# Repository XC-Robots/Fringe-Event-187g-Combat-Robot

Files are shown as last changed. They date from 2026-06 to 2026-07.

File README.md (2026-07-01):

# Fringe-Event-187g-Combat-Robot
Fringe Event is a combat robot in the fairyweight weight class. It uses a compliant shuffling mechanism for locomotion. Its main weapon is a pair of forks that fold inwards, trapping its opponents. Fringe Event, evident in the name, is inspired by and themed on the tv show Fringe. Normal fairyweight robots are 150g, so you might wonder why this one is more. Since Fringe Event is a shuffler, it gets a 1.25x weight bonus. The goal of this build is to experiment with different methods of locomotion and offensive mechanisms. Below is the final render of the bot:FringeEventRender

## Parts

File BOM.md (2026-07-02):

| Item | Individual Weight (g) | Quantity | Spare Quantity | Individual Cost ($) | Total Cost w/ Shipping ($) | Total Weight on bot (g)| Link | Version|
|---|---|---|---|---|---|---|---|---|
| Drive Motors | 15.2 | 2 | 0 | 19.00 |43.97 | 30.4 | https://turnabot.com/products/planetary-gearbox-high-power-n10-n20-and-n30-motors?variant=42952334540865 | N20 1300
| LiPo Battery 2S | 19 | 1 | 0 | 26.99 |29.08 | 19 | https://www.amazon.com/OVONIC-300mAh-Battery-Voltage-Package/dp/B0D2L17M8H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 |
| Drive ESC | 2.5 | 1 | 0 | 28.00 | 33.97 | 2.5 | https://turnabot.com/products/malenki-nano-integrated-6-channel-triple-electronic-speed-controller-receiver-combo |
| Power Switch | 2.15 | 1 | 0 | 9.00 | 14.00 | 2.15 | https://repeat-robotics.com/products/fingertech-switch
| TPU Chassis | 44.5 | 1 | 1 | - | - | 44.5 | - |
| TPU Servo Guard | 10 | 1 | 1 | - | - | 10 | - |
| TPU Legs | 1 | 12 | 12 | - | - | 12 | - |
| PLA Cams | 0.26 | 6 | 6 | - | - | 1.6 | - |
| PLA Motor Mounts | 9.6 | 2 | 2 | - | - | 19.2 | - |
| Standoffs | 1 | 5 | 5 | 0.74 |  | 5 | https://www.mcmaster.com/95947A013/ |
| Servo | 20 | 1 | 0 | 35.00 | 41.24 | 20 | https://turnabot.com/products/kst-ds215mg |
| Top plate | 6.33 | 1 | 1 | 9.99 | 10.76 | 6.33 | https://www.amazon.com/Zonon-Polycarbonate-Plastic-Resistant-Document/dp/B0DGGMP8QB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 |
| Bottom plate | 7.23 | 1 | 1 | (purchased w/ top plate) | (purchased w/ top plate) | 7.23 | https://www.amazon.com/Zonon-Polycarbonate-Plastic-Resistant-Document/dp/B0DGGMP8QB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 |
| Forks | 4 | 2 | 2 | 2.05 | 32.21 | 4 | Sendcutsend |
| **TOTALS** | - | - | - | - | 205.23 | 183.91 | - |

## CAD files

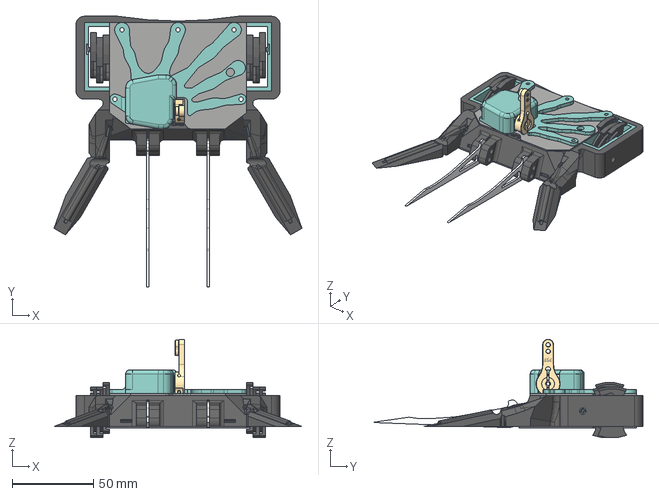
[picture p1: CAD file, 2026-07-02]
CAD/Fringe Event Full Bot.step
152.3 x 166.1 x 60.4 mm

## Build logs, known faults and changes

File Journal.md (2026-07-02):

Day 1, 6/28/26:    
Today I began working on the electronics layout of my robot. For decent pushing power and little weight usage I decided to go with planetary n20s for my robot's drive system. To keep things simple and compact, I am controlling these through a Malenki-Nano board, which handles both the drive controller and reciever jobs. To operate the hugging mechanism I am using a KST DS215MG servo, mainly for its speed and reliability. All this is powered by a 2S 300mAh battery. Below is my current electronics positioning. This took around 20 minutes of work.

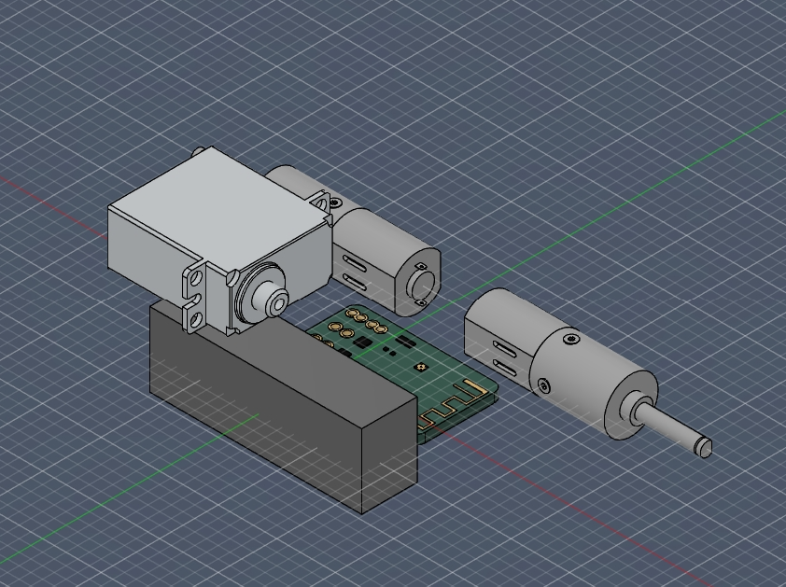
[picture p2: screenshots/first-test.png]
Electronics setup


Day 2, 6/29/26:
I designed a rough TPU chassis to fit around the electronics, as well as polycarbonate top and bottom plates. I decided to use M2.5 aluminum standoffs to hold everything together. This process took 37 minutes.
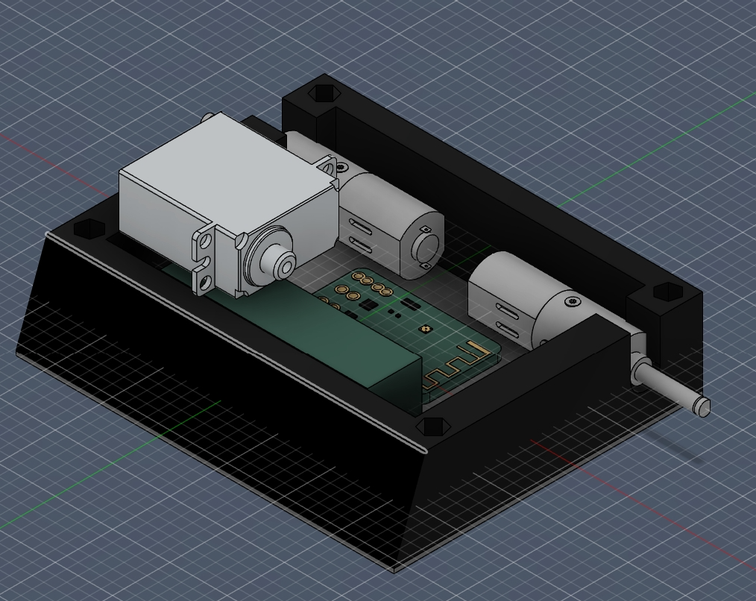
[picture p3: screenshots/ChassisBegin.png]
Chassis setup

Working on the basis of the drive motor mount and cam for the shuffler mechanism. The shuffler mechanism is inspired by this design: https://www.digikey.com/en/maker/tutorials/2024/how-to-make-a-robot-shuffler-mechanism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. I am planning on printing this out of PLA+ or PETG since this part is caged in TPU and therefore won't need to take a direct hit, and it'll keep things simple. Also made significant changes to chassis in order to fit this new portion. I removed the side walls and back wall, which I will add back in later once the essentials are in place. This has taken 45 minutes so far. Here is my motor mount:
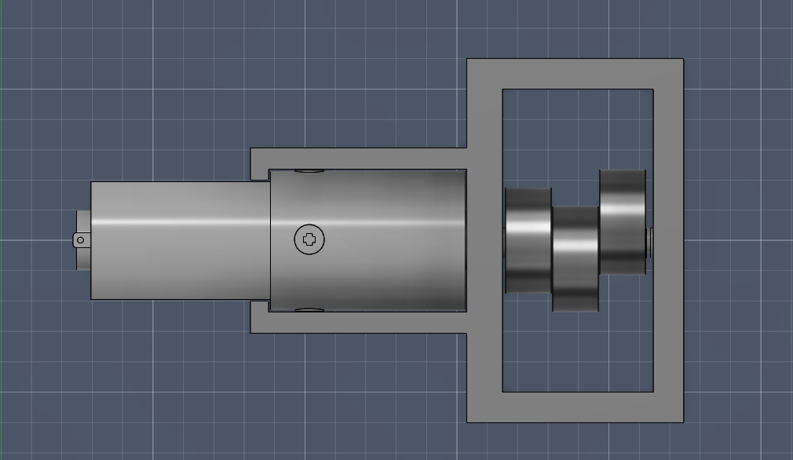
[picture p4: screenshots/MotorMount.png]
Motor

      I spent a good hour working on the shuffler legs, adjusting them to fit the robot. I went for three legs per side to enduce clean motion without using too much weight. Since I am using a compliant shuffler mechanism, I will be printing these legs out of TPU. I also remade the TPU chassis and armor, fitting it better to the overall design.
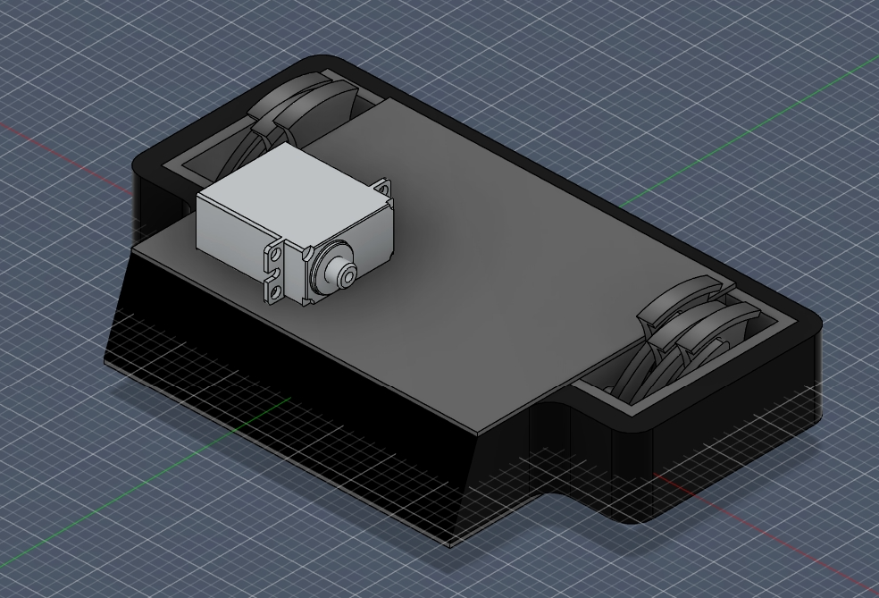
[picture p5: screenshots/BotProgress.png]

       I spent 36 minutes refining the details, mostly the coloration, of the robot. I also took the time to start on one of the hugger forks. These will hang around around the outside of the bot and then snap inwards when triggered by the servo. Just a rough draft right now.
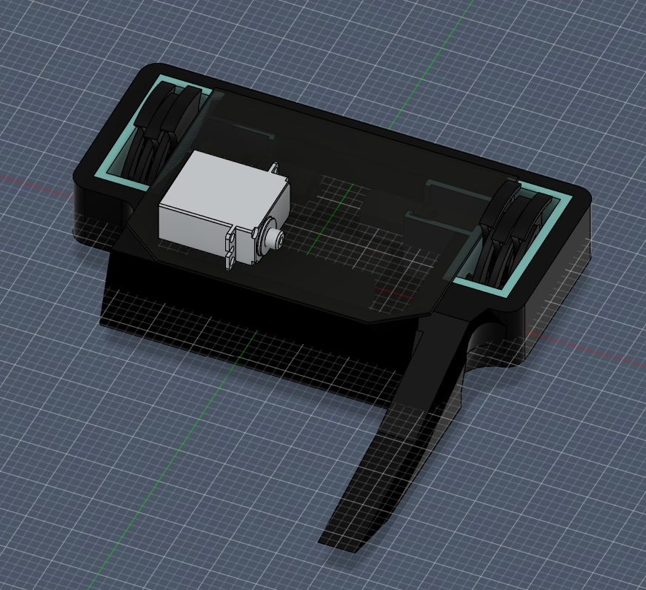
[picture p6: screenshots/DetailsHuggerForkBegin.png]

         Day 3, 6/30/26:
     I took the time to refine the current details in the robot, filleting and chamfering where needed. I also added the holes for the standoffs I'm going to use to connect the top and bottom plates, as well as refined the motor mounts and indented the back TPU armor (this with the purpose of saving weight and looking cooler). This process took 40 minutes. I spent another 34 minutes coming up with and editing a design for the inner forks. To compliment the hugger forks, I am using two standard forks between them, made out of 1.5mm aluminum. This will significantly increase the likelyhood of getting under enemy robots, which is crucial to combat robotics.

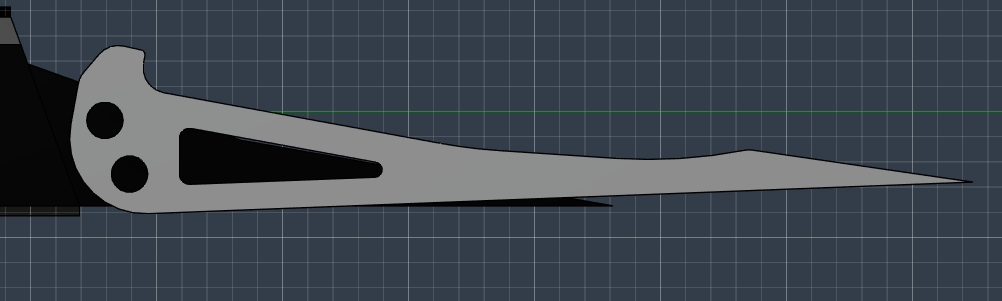
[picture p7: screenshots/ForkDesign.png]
Forks


I spent 26 minutes designing the fork mounts, where the forks connect to the chassis, and a TPU servo protector. The servo protector will both mount the servo to the robot and provide an extra layer of defense incase that part gets hit.
The Hugger forks weren't turning out how I wanted them to, so I took the time to reshape one side. Instead of going straight foward, the fork funnels outward, hopefully providing a better probability of sucess. Also, it looks way cooler and more unique. About 30 minutes to do this. Next I am going to create the holes to run string through the hugger arms, which is what will cause them to bend. 
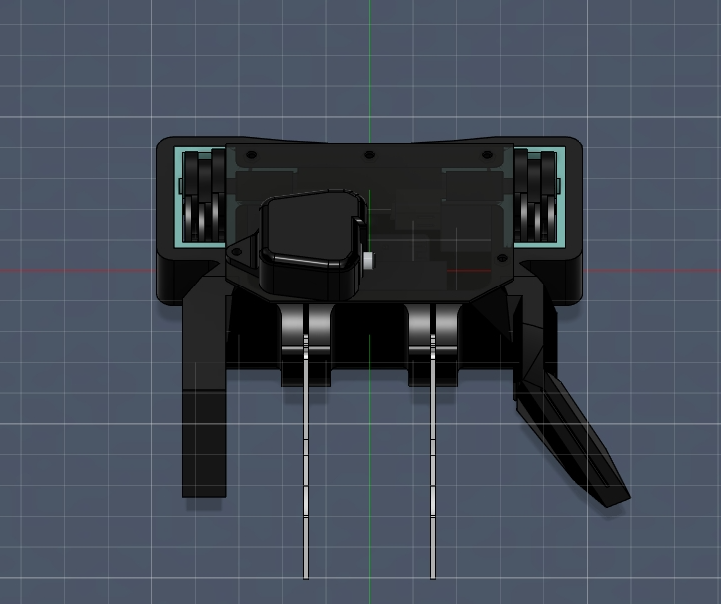
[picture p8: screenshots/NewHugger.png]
Hugger

            Day 4, 7/1/26:
            I am designing what are essentially tunnels for the string to go through for a few reasons. First off, these tunnels protect the string from attacks. Second, they help corral the string, making movements more consistent and accurate. These are essentially the arteries of the robot. I am running them from the tips of the hugger forks to the servo.
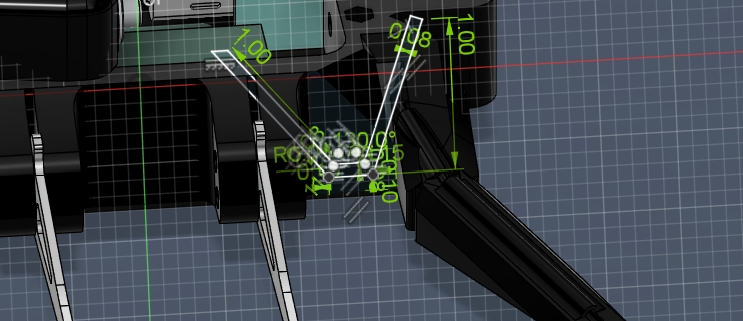
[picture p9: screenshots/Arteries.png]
String

            I spent 1 hour and 17 minutes this session finalizing the design. I adjusted the arteries so they reached the correct locations, then mirrored the new hugging fork to the other side. Next I got to work designing a decoration that was incorporated into the servo guard. I was going for a kind of 'cool hand' design, though I ended up with something more like 'feverish splat'. Oh well, still adds some nice detail to the bot. Each finger goes to a screw hole, which also helps mount the servo securely. I added a fingertech switch, which turns the bot on and off, because I forgot to earlier. I also added a battery wall in order to keep the electronics more organized. Finally, I cadded the servo horn on top. Now I need to make the wedge configuration, a different module more optimized for fighting horizontal weaponed robots.
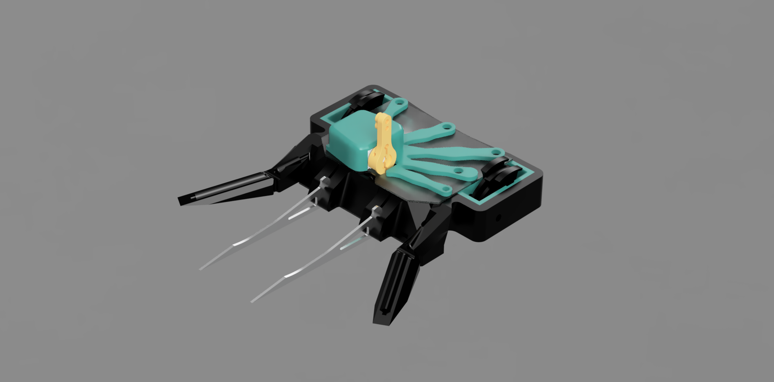
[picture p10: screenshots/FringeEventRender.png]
            
            Now it's just weight calcs from here (hopefully).
            Day 5, 7/2/26: Weights are in and, if accurate, the total weight of the bot is 182.65g. This is technically below the limit, but I don't want to go any heavier in case there is some variability in the calculations. Right now, though, Fringe Event is done.

            Total CAD time: 6hr, 41 min
            Total time (rough estimate): 9hr

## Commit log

2026-06-28 Add files via upload
    Day 1, 6/28/26
    I started planning out my electronics placement for the robot and overall proportions. I am using two planetary N20 motors for the drive system, controlled by a Malenki-nano. The hugger mechanism wil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
2026-07-02 Rename Fringe Event.step to CAD/Fringe Event.step
    [Fringe Event.step]
2026-07-02 Rename Fringe Event Full Bot.step to CAD/Fringe Event Full Bot.step
    [Fringe Event Full Bot.step]
2026-07-02 Rename CAD/Fringe Event Full Bot.step to Fringe Event Full Bot.step
    [Fringe Event Full Bot.step]
